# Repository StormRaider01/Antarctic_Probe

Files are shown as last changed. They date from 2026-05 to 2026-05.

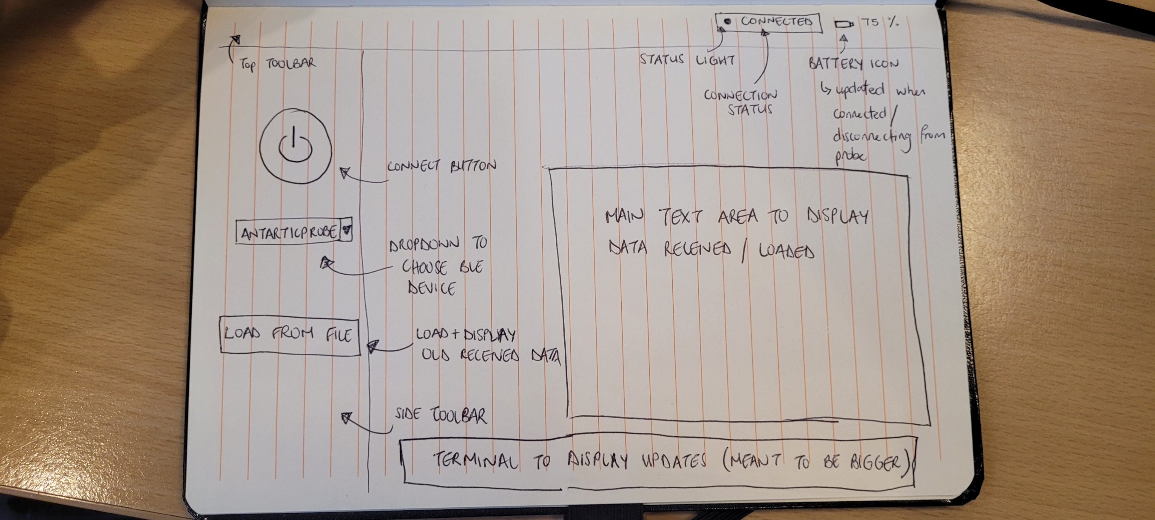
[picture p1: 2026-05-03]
GUI/GUI_idea.jpg

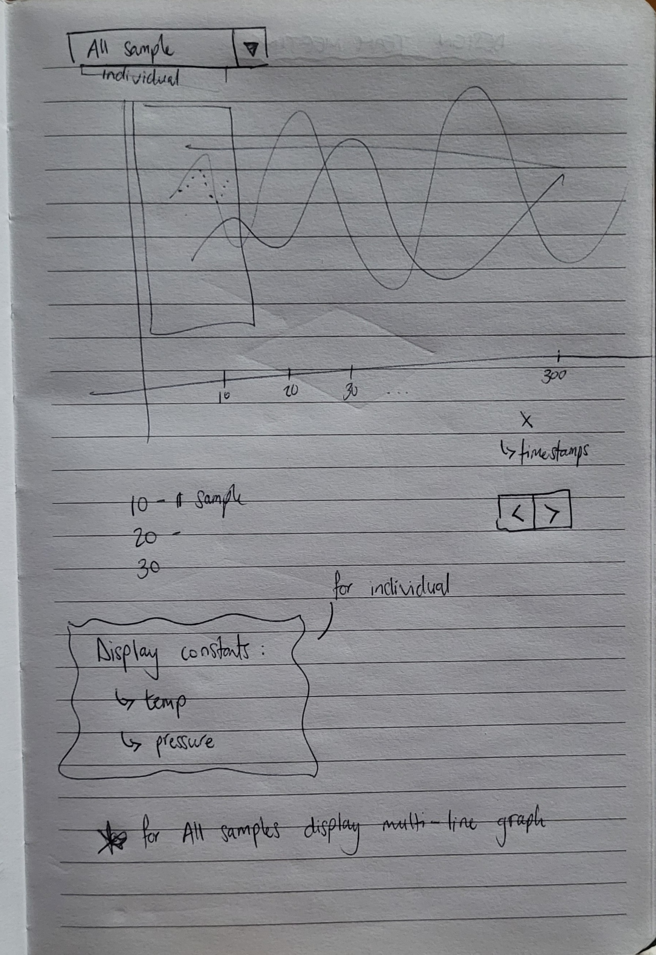
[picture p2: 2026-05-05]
GUI/Graph_tab.jpg

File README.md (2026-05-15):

# Antarctic Submersible Probe — Mission Control System

## Project Overview

This repository contains the integrated firmware, data pipeline, and GUI for a submersible Antarctic marine environmental probe system. The architecture represents the full integration of **Subsystem 1 (Wireless Communications)** and **Subsystem 2 (Edge Processing, Storage, and Machine Learning)**.

The system uses **ESP-NOW** for ultra-low-power wireless data transfer from a retrieved probe to a researcher's laptop, operating entirely **offline** with no internet dependency. Anomalies in microbial communities (detected via spectrometer spikes) are flagged instantly upon retrieval using an onboard offline Machine Learning model.

**Integrated System Flow:**
```text
Submersible Probe (ESP32-C6)
   ├── 3-State Firmware (Deep Sleep, Log, Offload)
   ├── Sensor readings parsed into 15-channel strings
   └── F-RAM (Simulated via RTC Memory)
        │
        │  [ESP-NOW Binary Protocol — ProbeRecord_t]
        ▼
Receiver Dongle (ESP32-C6 connected via USB)
   ├── Validates Checksums & Returns ACKs
   └── Serialises struct into CSV strings
        │
        │  [Serial/USB: 115200 baud]
        ▼
Local Mission Control GUI (Python)
   ├── Auto-connects to receiver dongle
   ├── Parses incoming data streams concurrently
   ├── Executes Scikit-Learn Isolation Forest Inference
   └── Visually flags [ANOMALY DETECTED] on GUI graphs
```

---

## Repository Structure

```text
├── Data Transfer Subsystem/
│   ├── Probe/
│   │   ├── Antarctic_probe.ino      # Main 3-state firmware loop
│   │   ├── espnow_transfer.cpp/.h   # ESP-NOW transmission logic
│   │   ├── fram_manager.cpp/.h      # F-RAM logging and struct parsing
│   │   └── data_packet.h            # Shared binary wire format (15 fields)
│   └── Receiver/
│       └── receiver_dongle.ino      # ESP-NOW receiver and Serial forwarder
└── GUI/
    ├── GUI.py                       # Main frontend dashboard
    ├── Backend.py                   # Serial comms, async sync_probe, anomaly evaluation
    └── ml_backend/                  
        ├── anomaly_detector.py      # MarineAnomalyDetector class wrapper
        ├── train_model.py           # Isolation Forest training script
        ├── generate_dummy_data.py   # Synthesises 15-channel marine data
        └── anomaly_model.joblib     # Persisted offline ML model
```

---

## Technical Architecture

### 1. Firmware & Storage (SS2)
- **Non-Blocking Architecture:** The probe operates a strict 3-state loop (`DEEP_SLEEP`, `WAKE_AND_LOG`, `OFFLOAD`). It uses hardware timer wakeups and GPIO interrupts (reed switch) to eliminate `delay()` calls entirely, preserving the LTO battery.
- **F-RAM Simulation:** Sensor arrays (Temp, Pressure, and 11x Spectrometer channels) are saved to RTC memory across deep sleep cycles to simulate high-speed, non-volatile F-RAM.
- **Data Packaging:** When retrieved, `fram_manager.cpp` inflates the stored strings back into binary `ProbeRecord_t` structs (incorporating 11 spectrometer arrays) for transmission.

### 2. ESP-NOW Wireless Transfer (SS1)
- **Binary Wire Format:** Uses packed C-structs (`ProbeRecord_t`) with XOR checksums to maximize MTU efficiency over the 2.4GHz spectrum.
- **Reliability:** Implements application-layer ACKs and automatic retries to ensure no packet drops between the probe and receiver dongle.

### 3. Mission Control GUI & Backend (SS1 + SS2)
- **Concurrency:** `Backend.py` uses threaded asynchronous loops to ensure the `customtkinter` frontend remains responsive while streaming high-speed serial data.
- **Auto-Discovery:** Performs DTR/RTS serial handshaking to locate the ESP32 receiver dongle automatically without manual COM port selection.

### 4. Edge Machine Learning (SS2)
- **Algorithm:** An Unsupervised `IsolationForest` identifies outliers based on 13 environmental features (dropping timestamps/IDs).
- **Inference Speed:** Executed directly on incoming serial packets within `Backend.py` via `anomaly_detector.py`. Average inference time is < 0.02 seconds per packet, satisfying real-time mission constraints.
- **Visualisation:** The GUI parses the boolean `is_anomaly` flags to plot outlier samples in high-contrast red over the Matplotlib telemetry graphs.

---

## How to Run

### 1. Setup the Hardware
1. Flash `Antarctic_probe.ino` to the primary ESP32-C6 (Probe).
2. Flash `receiver_dongle.ino` to the secondary ESP32-C6 (Receiver).
3. Connect the Receiver to your laptop via USB.

### 2. Setup the Python Environment
```bash
cd GUI
pip install -r requirements.txt
# Ensure scikit-learn, pandas, numpy, serial, customtkinter, matplotlib are installed
```

### 3. Start Mission Control
```bash
python GUI.py
```
- Click **"Connect"**. The backend will automatically handshake with the receiver dongle.
- Click **"Retrieve Data"**. 
- Simulate the probe retrieval by triggering GPIO 9 (Reed Switch) on the probe hardware. The F-RAM records will transfer wirelessly, be evaluated by the ML model, and plot directly to the dashboard.

### 4. Software Simulation Mode (Dev Mode)
If you do not have the physical hardware connected, you can simulate the full data processing and ML pipeline locally:
- Open the GUI (`python GUI.py`).
- Click **"🧪 Dev Mode: Simulate"** in the sidebar.
- The GUI will ingest the local synthetic dataset (`dummy_marine_data.csv`), simulating an ESP-NOW data stream at 0.5-second intervals. 
- Use the **Playback Control Panel** (Pause/Play, Restart, Stop) that appears to interactively control the simulation flow. Watch the graphs update live and verify the red anomaly flags without needing the physical ESP32 boards.

### 5. Hardware-in-the-Loop (HITL) Debug Mode
For physical validation without physical sensors or a magnetic switch:
1. Open `Data Transfer Subsystem/Probe/Antarctic_probe.ino`.
2. Ensure `#define DEBUG_MODE 1` is set at the top.
3. Flash the firmware to your ESP32-C6.
4. **Timer Validation**: Watch the Serial Monitor. The board will wake every 5 seconds, log a dummy record to RTC memory, and return to sleep.
5. **Interrupt Validation**: Press the physical **BOOT button** (GPIO 9) on the FireBeetle 2. This simulates the magnetic reed switch. Upon waking, the board will enter the `OFFLOAD` state and dump all accumulated RTC memory records to the Serial Monitor.

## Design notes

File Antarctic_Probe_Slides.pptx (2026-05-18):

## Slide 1

Antarctic Microbial Sensor

Autonomous Marine Environmental Monitoring System

EEE4113F · Group 14 · University of Cape Town

Devon Clark · Joshua Naidoo · Kiyuran Naidoo · Saeed Solomon

Supervised by Dr Emma Rocke · MARiS, UCT

May 2026

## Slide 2

Background & Motivation

Why does Antarctic marine monitoring matter?

THE OCEAN'S EARLY-WARNING SYSTEM

• Marine microbes are the 'invisible engines' of the ocean ecosystem
• They are the first biological indicators of climate change and pollution
• Dr Emma Rocke (MARiS, UCT) studies microbial dynamics across Antarctic & Southern Oceans
• Early detection of harmful algal blooms requires continuous, high-resolution data

THE 'WINTER DATA GAP'

• Current practice relies on expensive, infrequent research cruises
• Austral winter (-30 °C, expanding sea ice) makes the region inaccessible for months
• This creates a critical 'winter data gap' — the time most valuable for early warnings
• Human presence in the Antarctic is hazardous, costly, and logistically prohibitive

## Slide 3

Project Objectives

Design a low-cost, autonomous bipartite marine monitoring system

① Continuous Sensing

Acquire chlorophyll-a fluorescence, temperature, and depth as microbial community proxies

② Reliable Storage

Store sensor data in non-volatile memory under extreme sub-zero conditions during a dive

③ Wireless Offload

Transfer stored data wirelessly to a researcher's laptop upon probe retrieval — no physical port

④ Offline Intelligence

Process data locally using ML anomaly detection to identify ecological events — fully offline

⑤ Annual Autonomy

Sustain operation for up to 12 months on a single primary battery without human maintenance

⑥ Low Cost & Safe

Total component cost ≤ R2 000; hand-deployable by one non-specialist from a vessel of opportunity

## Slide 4

System Architecture Overview

A bipartite store-and-forward system deployed from vessels of opportunity

The system comprises two hardware nodes and one software platform. The submersible probe collects data autonomously underwater, then offloads wirelessly to a USB dongle connected to the researcher's laptop.

SUBMERSIBLE PROBE

• ESP32-C6 (FireBeetle 2)
• FRAM non-volatile storage
• AS7341 spectral sensor
• DS18B20 temperature
• Pressure/depth sensor
• Li-SOCl₂ primary battery
• Thermal insulation shell

ESP-NOW WIRELESS LINK

• Connectionless data-link protocol
• 100 m range; ultra-low power
• CRC-16 packet integrity check
• Reed switch wakeup from deep sleep
• ACK/NACK retry mechanism
• < 60 s full data offload

MISSION CONTROL (LAPTOP)

• Receiver dongle (ESP32-C6 via USB)
• Python GUI (CustomTkinter)
• Raw data table + interactive graphs
• Isolation Forest + XAI anomaly detection
• Save / load session files
• 100 % offline — no internet required

⇌ ESP-NOW

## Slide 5

Subsystem 1 — Data Transfer & Visualisation

Saeed Solomon · ESP-NOW wireless protocol + Mission Control GUI

PROTOCOL SELECTION

• NFC — ruled out: strict proximity & orientation requirements
• BLE — implemented but abandoned: ESP32-C6 stack immaturity
• ESP-NOW — selected: proven reliability, 100 m range, ultra-low power

PROBE COMMAND FLOW

• [CMD]:CONNECT — verify link, update battery level on GUI
• [CMD]:PREPARE — reset FRAM, store session timestamp
• [CMD]:RETRIEVE — stream all records with CRC-16 check
• [CMD]:DISCONNECT — power down radio to conserve battery

RESULTS

• 1.2 % avg data error (spec: < 5 %)
• 8 s wake-to-advertising (spec: < 10 s)
• All 7 ATPs passed

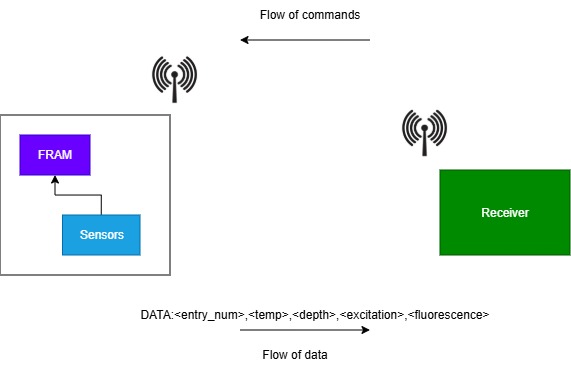
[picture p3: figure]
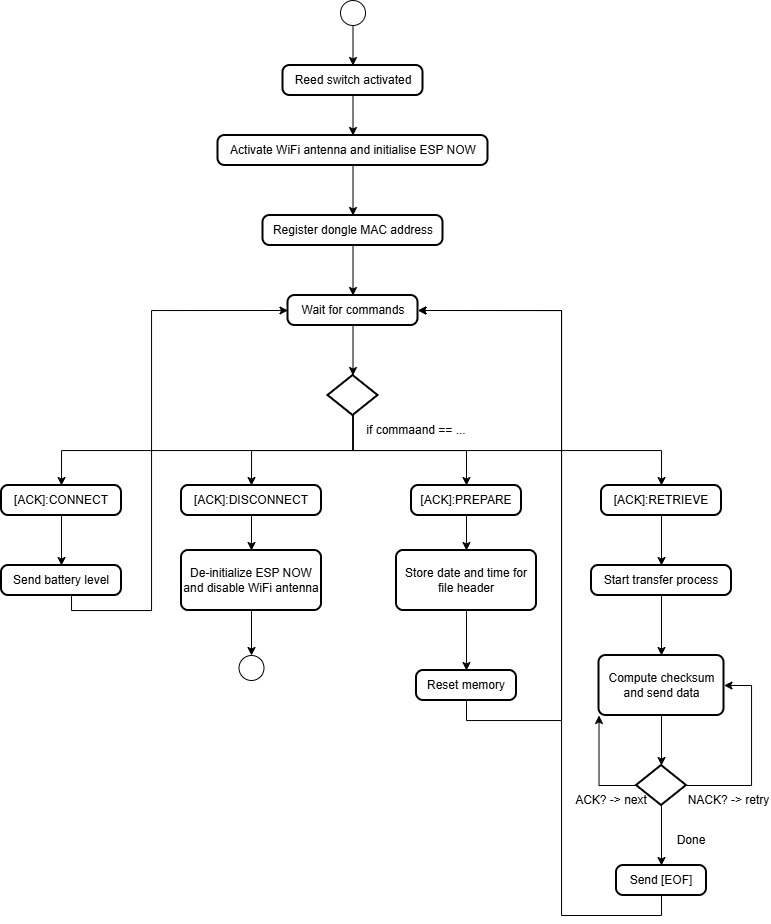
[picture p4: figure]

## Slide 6

Mission Control GUI

Fully offline Python desktop application — CustomTkinter + Matplotlib

KEY FEATURES

• Top toolbar shows connection status and battery percentage
• Sidebar: Connect / Prepare Dive / Retrieve Data / Dev Mode / Save & Load
• Raw Data tab — scrollable table of all 14 sensor channels per record
• Graph tab — interactive time-series with All Samples or per-Group view
• Status log at the bottom prints timestamped system events
• Anomaly markers (red dots) overlaid on graphs by the ML backend

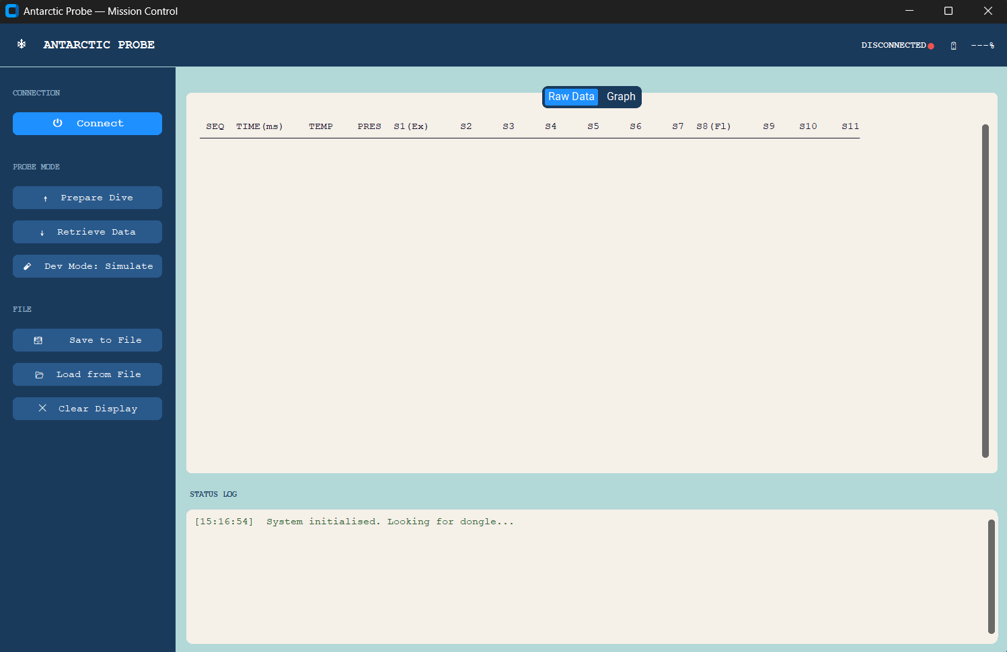
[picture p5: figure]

Raw Data tab

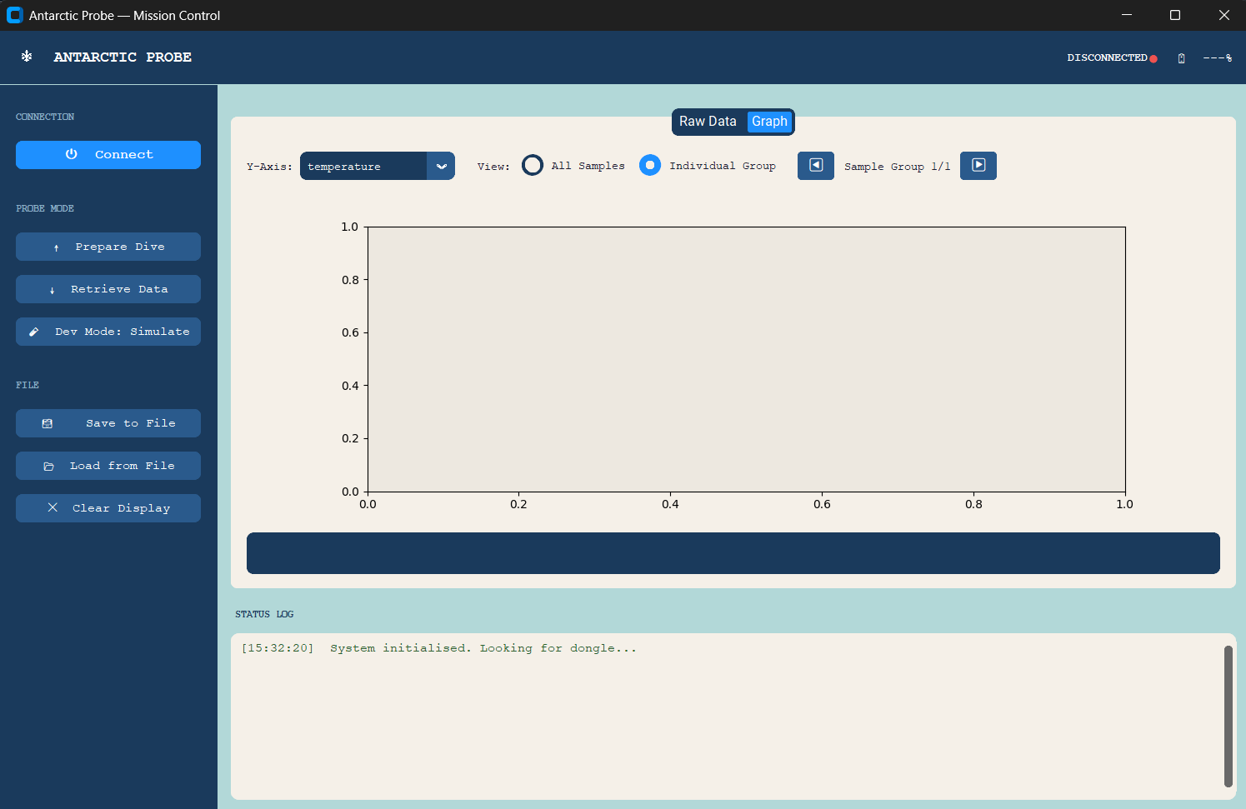
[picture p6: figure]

Graph tab

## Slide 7

Subsystem 2 — Edge Architecture & Explainable AI

Kiyuran Naidoo · On-probe firmware lifecycle + offline ML anomaly detection

4-STATE FIRMWARE LIFECYCLE

• STATE_IDLE — deep sleep on LP-IO, woken by magnetic reed switch
• STATE_ARMED — sinking delay (15 min) before data acquisition begins
• STATE_LOGGING — periodic measurement cycles; records written to FRAM
• STATE_OFFLOAD — activates ESP-NOW; awaits [CMD]:RETRIEVE from GUI

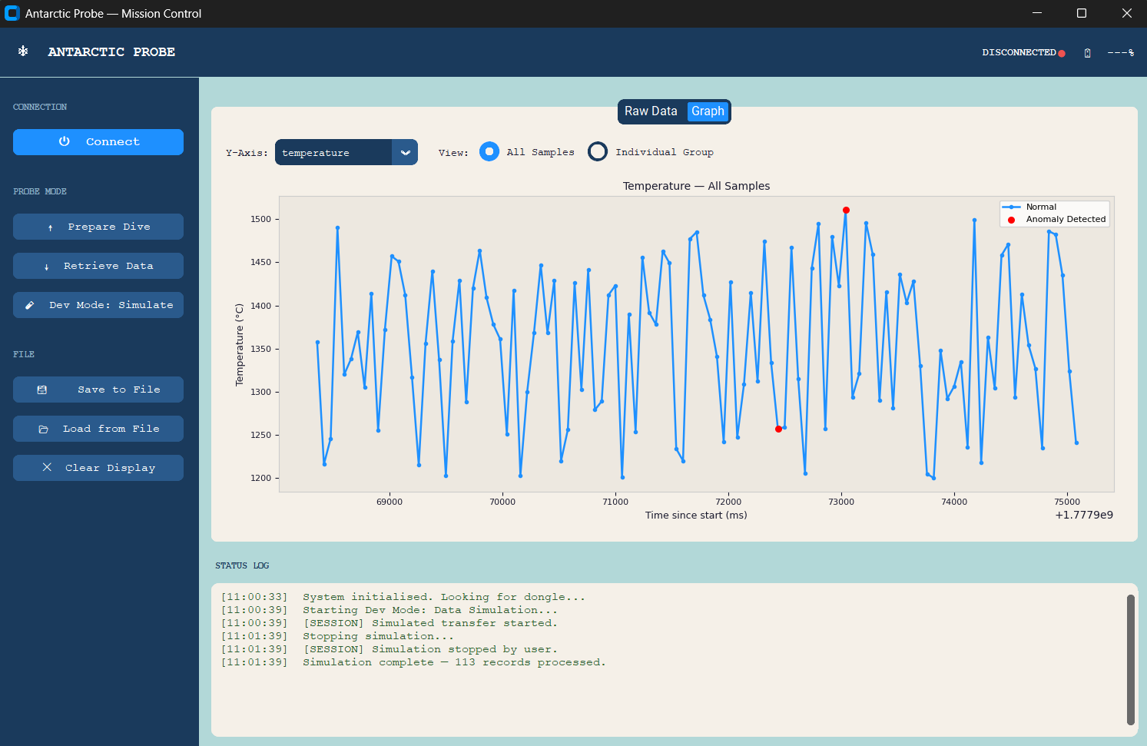
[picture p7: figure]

Mission Control graph: 113 records with anomalies flagged in red by the MarineAnomalyDetector

MEMORY — FERROELECTRIC RAM (FRAM)

• 10 mA write current vs 100 mA for SD card
• Operating range: -55 °C to +85 °C
• Data preserved across deep sleep resets (RTC SRAM)
• 58-byte fixed MTU per record, 14 sensor values

EXPLAINABLE AI (XAI) ENGINE

• Isolation Forest: anomaly isolation via random decision trees — O(n log n)
• Post-hoc deterministic ruleset: classifies Phytoplankton / Cyanobacteria / CDOM
• 92 % accuracy, 0 false positives, ~0.008 s inference (spec: < 2 s)

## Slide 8

Subsystem 3 — Power & Thermal Management

Joshua Naidoo · 365-day autonomy in Antarctic cryogenic conditions

Split-rail power schematic: ER14505 battery → MCP1700 LDOs → ESP32-C6 + FRAM + Sensors

ENERGY ARCHITECTURE

• ER14505 Li-SOCl₂ battery — operational down to -55 °C
• Nominal 2 400 mAh; 50 % capacity derated for -50 °C
• MCP1700 LDO: 1.6 µA quiescent vs 5 mA for LM7805
• FireBeetle 2 ESP32-C6: 10 µA deep sleep vs 10 mA (DevKit)
• Split-rail: 3.3 V always-on rail + 5 V switched sensor rail
• P-MOSFET (AO3401A) power gate — GPIO-controlled sensor isolation
• ~22 measurement cycles/day over 365-day mission verified

THERMAL 'HUDDLE' STRATEGY

• Layer 1 — Aluminium foil tape: reflects infrared radiation
• Layer 2 — EWELDH010 foam: stagnant air pockets, high thermal resistance
• RF window: 20 mm foil gap allows 2.4 GHz ESP-NOW signal to escape
• MCP1700 regulators thermally bonded to battery stack (self-heating)
• Result: internal core held at -12 °C after 6 h cold-soak at -30 °C
• 16.8 µA measured standby current — within 20 µA specification

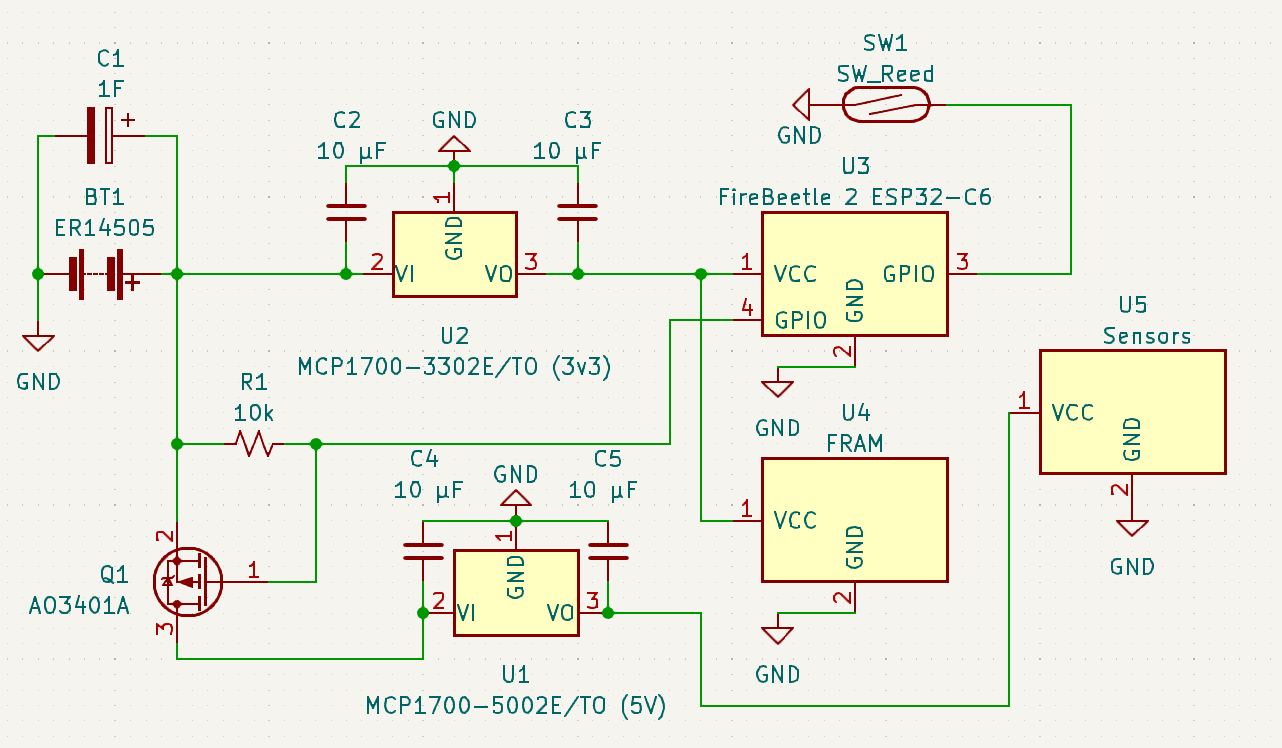
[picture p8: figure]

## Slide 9

Subsystem 4 — Sensors & Housing

Devon Clark · Chlorophyll fluorometer, temperature, depth, waterproof PVC enclosure

SENSOR SUITE

• AS7341 — 11-channel spectral sensor; 445 nm excitation, 680 nm fluorescence channels
• CZ104BC — 460 nm blue LED excitation (5 500–6 000 mcd); matches chlorophyll-a peak
• DS18B20 — waterproof 1-Wire digital; factory-calibrated; ±0.4 °C achieved
• Analog pressure sensor — 0–120 m range; R² > 0.99 depth linearity
• 11-step PWM ramp algorithm to optimise fluorometer sensitivity

WATERPROOF HOUSING

• 50 mm OD PVC pipe main body (46.8 mm ID, 250 mm length)
• FDM 3D-printed PLA end caps with 4 perimeters (SLA recommended for production)
• Friction-fit double O-ring seal — field serviceable, no tools required
• Negatively buoyant — self-sinking with ballast weights
• Waterproof to 1 m for 30 min (prototype validation)
• Total system cost: < R2 000 · Mass: < 1 kg

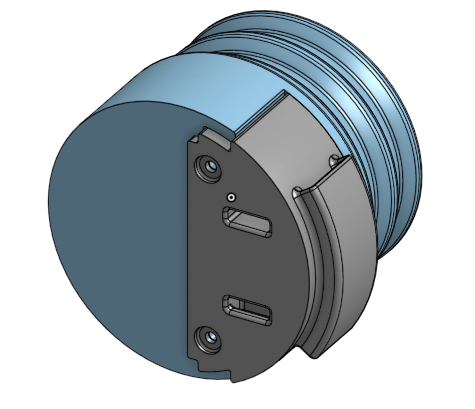
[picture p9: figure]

Rear end cap (sealed side)

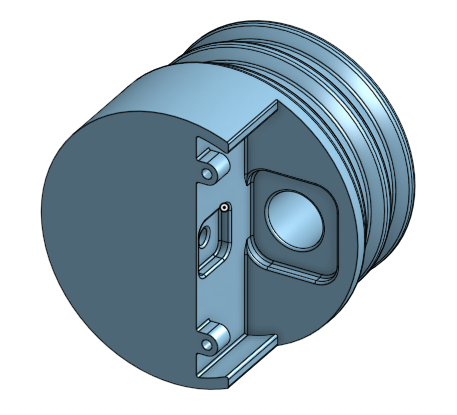
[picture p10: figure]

Front end cap (sensor window side)

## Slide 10

System Results & Validation

All subsystem acceptance test procedures passed

Data Transfer
& Visualisation

• 1.2 % avg data error (spec: < 5 %)
• 8 s wake-to-advertising (spec: < 10 s)
• 100 m operational range (spec: > 10 m)
• All 7 ATPs passed
• Fully offline GUI operation confirmed

Edge Architecture
& Explainable AI

• FRAM data intact across all deep sleep cycles
• 4-state lifecycle validated via HITL serial telemetry
• 92 % XAI classification accuracy, 0 false positives
• 0.008 s inference per record (spec: < 2 s)
• All 4 ATPs passed

Power & Thermal
Management

• 16.8 µA measured standby (spec: ≤ 20 µA)
• -12 °C core after 6 h cold-soak at -30 °C
• 3.3 V & 5.0 V rails stable across full discharge
• P-MOSFET gate: sensor current drops to 0 µA on GPIO
• All 5 ATPs passed

Sensors
& Housing

• Fluorescence ratio monotonically increases down to 1/32 dilution
• Temperature accuracy ±0.4 °C (spec: ±0.5 °C)
• Depth linearity R² > 0.99 (spec: R² > 0.99)
• Waterproof at 1 m for 30 min — no ingress
• All 8 ATPs passed · Total cost < R2 000

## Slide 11

Conclusions & Future Work

A functional, integrated Antarctic monitoring system demonstrated across all four subsystems

CONCLUSIONS

• A fully integrated bipartite probe system was designed and demonstrated
• Sensor data is acquired, stored in FRAM, and wirelessly offloaded to a laptop GUI
• ML-based anomaly detection operates entirely offline on standard hardware
• System is hand-deployable by one non-specialist from a vessel of opportunity
• Annual autonomy validated through energy modelling and cold-soak testing
• Total cost within R2 000 budget; fits within 50 mm OD PVC housing
• All 24 acceptance test procedures across four subsystems passed

FUTURE WORK

• Migrate to BLE once ESP32-C6 NimBLE stack matures (remove dongle requirement)
• SLA resin end caps for long-term immersion (replace FDM PLA)
• Absolute chlorophyll calibration using field samples
• Extend depth rating beyond 2 m prototype limit
• Add dissolved oxygen & nutrient sensors within revised budget
• LoRaWAN / NVIS relay from docking station to mainland research facility
• Satellite uplink for real-time data access during deployment

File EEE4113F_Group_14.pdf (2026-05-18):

# Antarctic Microbial Sensor

# Group 14


Prepared by:
Devon Clark
Joshua Naidoo
Kiyuran Naidoo
Saeed Solomon

Prepared for:
EEE4113F
Department of Electrical Engineering University of Cape Town

May 18, 2026

# Declaration

1. I know that plagiarism is wrong. Plagiarism is to use another’s work and pretend that it is one’s own.
2. I have used the IEEE convention for citation and referencing. Each contribution to, and quotation in, this report from the work(s) of other people has been attributed, and has been cited and referenced.
3. This report is my own work.
4. I have not allowed, and will not allow, anyone to copy my work with the intention of passing it off as their own work or part thereof.

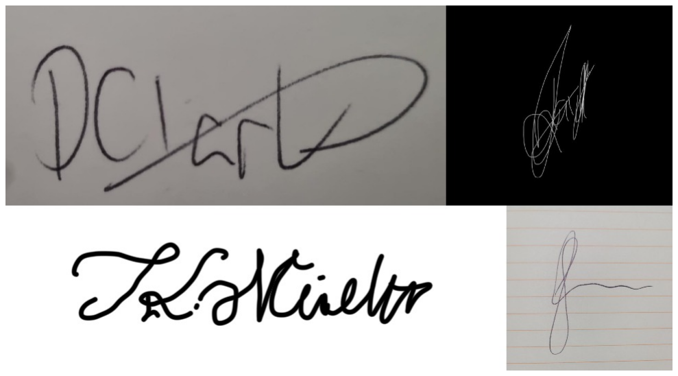
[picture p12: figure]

May 18, 2026

Devon Clark | Joshua Naidoo | Kiyuran Naidoo | Saeed Solomon Date

ii

# Contents

Abbreviations | vii
1 Introduction | 1
2 Literature Review | 3
3 Data Transfer and Visualisation | 14

iii

Contents

4 Edge Architecture and Explainable AI | 26
4.7.1 | Onboard Firmware and State Machine Verification (ATP-01 and ATP-02) . . . | 33
4.7.2 | Localised Edge Machine Learning and XAI Engine Validation (ATP-03 and
5 Power and Thermal Subsystem | 36

iv

Contents

6 Sensors and Housing | 45
7 Conclusions | 54

v

Contents

8 Recommendations | 56
9 Appendix | 60
A Dev Mode: Simulated Data Screenshots | 61
B Evidence of GA | 64
Bibliography | 65

vi

# Abbreviations

ANN Artificial Neural Network

ATP Acceptance Test Procedure

BLE Bluetooth Low Energy

CNN Convolutional Neural Network

CTD Conductivity, Temperature, Depth

DL Deep Learning

DMS Data Management Subsystem

ECR Edge Computing-RESTful

eNVM Embedded Non-Volatile Memory

GUI Graphical User Interface

IDE Integrated Development Environment

IoT Internet of Things

LAMP Loop-Mediated Isothermal Amplification

LED Light Emitting Diode

LoRaWAN Long Range Wide Area Network

LPWAN Low-Power Wide-Area Network

MEMS Micro-Electro-Mechanical Systems

ML Machine Learning

MRAM Magnetoresistive Random Access Memory

NFC Near-Field Communication

NVIS Near Vertical Incidence Skywave

vii

Abbreviations

PCB Printed Circuit Board

PCM Phase Change Materials

PDMS Polydimethylsiloxane

ROV Remotely Operated Vehicle

SLA Stereolithography

STT-MRAM Spin-Transfer Torque MRAM

SVM Support Vector Machine

SWPDT Simultaneous Wireless Power and Data Transfer

UI User interface

USB-C Universal Serial Bus Type-C

USV Unmanned Surface Vehicle

Wi-Fi Wireless Fidelity

viii

# Chapter 1

# Introduction

### 1.1 Background

Marine microorganisms are the foundational drivers of the ocean ecosystem, mediating global biogeochemical cycles and acting as the first responders to environmental stressors such as climate change and anthropogenic pollution. As Dr Emma Rocke, a marine microbiologist at the Marine and Antarctic Research for Innovation and Sustainability (MARiS) institute at the University of Cape

Town, describes it: “Microbes are the invisible engines of the ocean ecosystem.” Her research spans the Benguela Upwelling System, the Indian Ocean, and the Antarctic and Southern Ocean, where microbial community dynamics serve as the earliest available proxy for broader ecological shifts.

Gathering the continuous, high-resolution data required to detect these shifts presents a fundamental challenge in the Antarctic region. Current practice relies on research cruises that are expensive, infrequent, and offer only limited spatial coverage. The austral winter exacerbates this shortfall severely: expanding sea ice, temperatures routinely below −30 ◦C, and inclement weather render the

region physically inaccessible for months at a time, creating what is widely termed the winter data gap. Critically, this period of observational absence coincides with the time at which early detection of harmful algal blooms and ecosystem disturbances would be most valuable. The reliance on human operators to bridge this gap exposes researchers to acute physical danger, extreme psychological strain, and high logistical cost, while still failing to produce the temporal continuity the science demands.

### 1.2 Objectives

The primary objective of this project is to design and demonstrate a low-cost, autonomous bipartite marine environmental monitoring system that can be deployed from vessels of opportunity — including fishing vessels, sailing yachts, and research cruises — by non-specialist operators, thereby removing the need for dedicated human presence in hazardous Antarctic conditions. The system must:

1. Acquire continuous optical and physical sensor data (chlorophyll-a fluorescence, temperature, and depth) as proxies for microbial community dynamics.
2. Store acquired data reliably in non-volatile memory under extreme sub-zero conditions for the duration of a dive.
3. Transfer the stored data wirelessly to a researcher’s laptop upon probe retrieval, without requiring

1.3. System Requirements

a physical port on the probe enclosure.

4. Process the retrieved data locally, using machine learning anomaly detection to identify ecologically significant events entirely offline.
5. Sustain operation for up to twelve months on a single primary battery set without human maintenance.

### 1.3 System Requirements

The system must operate across two extreme thermal regimes: seawater approaching −1.8

◦C during
submersion and ambient air down to −30 ◦C upon retrieval to the vessel deck. The probe enclosure

must withstand shallow-water pressure without water ingress, and all electronics must remain functional throughout. The complete system must fit within a 50 mm outer-diameter PVC pipe housing, be hand-deployable by a single operator, and have a total component cost not exceeding R2000. Data transfer between the probe and the laptop must complete within 60 seconds of connection, and the Mission Control graphical user interface must operate fully offline without any dependency on internet connectivity.

### 1.4 Scope and Limitations

This project addresses the sensor-to-laptop data pipeline and does not extend to long-range satellite transmission to mainland research facilities, which is identified as future work. The prototype targets near-surface deployments of up to 2 m depth; the design is architecturally scalable to greater depths but hardware validation at depth is beyond the present scope. Dissolved oxygen and nutrient sensors are excluded due to budget constraints, with chlorophyll-a fluorescence retained as the primary microbial proxy. Wireless charging of the probe battery, initially proposed as part of the docking station concept, was descoped following the removal of the docking station from the architecture; the probe instead uses a primary Lithium Thionyl Chloride battery rated for twelve months of autonomous operation.

### 1.5 Report Outline

This report is structured as follows. Chapter ?? presents the literature review, surveying candidate data transmission protocols, embedded memory architectures, extreme-cold power systems, and marine sensing and housing methodologies to ground each design decision in the existing body of knowledge. Chapters ?? through ?? cover the four engineering subsystems in depth: Data Transfer and Visualisation (Chapter ??), Edge Architecture and Explainable AI (Chapter ??), Power and Thermal Management (Chapter ??), and Sensors and Housing (Chapter ??). Each chapter follows a consistent structure: requirements analysis, design choices with justification, final implementation, and acceptance test results. Chapter 7 draws overall conclusions and Chapter 8 identifies directions for future work.

# Chapter 2

# Literature Review

### 2.1 Introduction and Operational Context

The Antarctic marine ecosystem plays a critical role in global climate regulation, with marine microbes acting as the ocean’s primary early warning system for environmental shifts and pollution. However, gathering continuous, real-time biological data in this region is severely constrained by the ‘winter gap’, a period where extreme cold, sea-ice expansion, and severe weather make traditional research cruises prohibitively dangerous and expensive. Consequently, the reliance on infrequent manual sampling exposes marine researchers to immense physical and psychological risks while leaving vast spatial and temporal gaps in the ecological data pipeline.

To address this observational bottleneck without relying on highly complex, fully autonomous ocean gliders, a bipartite measurement system deployed from ‘vessels of opportunity’ (such as research cruises, fishing vessels or sailing yachts) presents a highly feasible engineering solution. This concept comprises a deck-bound docking station and a submersible measurement probe. The probe is lowered into the ocean via a tether to log localised environmental data, after which it is retracted to the docking station to securely transfer the telemetry for advanced on-board processing.

Operating a sophisticated electronic system in an environment where ambient temperatures drop below -30°C and seawater approaches -1.8°C introduces severe, multi-disciplinary engineering challenges. This literature review evaluates current academic research to inform the design of this bipartite system. The review is structured to analyse four critical domains: short-range data transmission protocols to bridge the two subsystems (Section 1.2), edge computing architectures and robust embedded memory to manage the massive datasets (Section 1.3), specialised battery chemistries and thermal management techniques to ensure survivability (Section 1.4), and the physical sensing modalities, waterproofing, and tethering mechanics required for reliable marine deployment (Section 1.5).

### 2.2 Data Transmission Subsystem

Operation of electrical systems in the extreme environmental conditions of Antarctica presents numerous engineering challenges. Liu et al. identifies sensor drift, packaging cost, and sea-water corrosion as significant factors that affect system performance in such climates [1]. Similarly, Uhm et al. highlights the necessity of active temperature control and thorough insulation of internal hardware to sustain the prolonged operation of a robotic system tested in Antarctica [2]. These findings highlight the dangers

2.2. Data Transmission Subsystem

posed by exposed ports or incomplete enclosures, which can allow the harsh Antarctic environment to compromise internal components. The following subsections examine candidate data transmission methods for communication between the measurement probe and the main docking station subsystem.

### 2.2.1 Wired Protocols

A tethered connection between the measurement probe and the docking station was initially proposed to enable real-time data communication. However, several critical concerns were identified: the potentially large and variable distance a tether would need to span depending on whether the solution is deployed on a large research vessel or a smaller fishing vessel; signal integrity degradation over long cable runs; and the exorbitant cost of thermally insulated, electrical cabling needed to transmit data in the Antarctic cold. Additional concerns included the risk of undetected faults developing over time due to limited maintenance access, which could result in silent data loss or corruption. For these reasons, long-range tethered solutions were ruled out in favour of short-range wired protocols to transfer data between the two subsystems once the measurement probe has returned from deployment. Table 2.1 summarises the characteristics of several candidate short-range wired protocols [3].

Name | Duplex | Max speed (Kbps) | Max distance (ft)
RS-232 | Full | 20 | 30
RS-422 | Half | 10000 | 4000
RS-485 | Half | 10000 | 4000
2C I | Half | 3400 | <>
SPI | Full | > 1000 | <>

Table 2.1: Short-range wired protocol comparison [3]

A further short-range protocol not listed in Table 2.1 is Universal Serial Bus Type-C (USB-C), which has become a widely adopted industry standard owing to its plug-and-play capability, high data transfer speeds, and versatility across connection types [3].

### 2.2.2 Wireless Protocols

Because the measurement probe operates while submerged and the docking station remains above the waterline, long-range wireless communication between them during deployment is not feasible. This is primarily due to the pronounced difference in electromagnetic signal propagation between water and air, which severely attenuates radio-frequency signals at depth [4]. Consequently, a short-range wireless protocol - employed once the measurement probe has surfaced and returned to the docking station
- represents the most viable wireless approach. A long-range wireless solution was also considered, following the approach of Porte et al., who employed Near Vertical Incidence Skywave (NVIS) to relay data directly to a remote research station [5]. This architecture would have eliminated the need for a docking station subsystem entirely by transmitting data directly to a research base. However, it would have imposed significantly greater power, environmental protection and hardware requirements on the measurement probe, including the need for the either human personnel or another subsystem to ensure the positioning for NVIS to take place [5]. Although this approach was not adopted for

2.3. Edge Architecture and Data Management

the measurement probe, it remains a viable option for the docking station subsystem to relay data onward after the initial sensor-to-docking-station transfer. Table 2.2 presents a comparison of candidate short-range wireless protocols, based on the comparative study conducted by Vidakis et al. [6].

Name | Range (m) | Frequency | Transmission time (s) | Power consumption
Bluetooth | 100 | 2.4 GHz | 24 Mbit/s | Medium
BLE | 60 | 2.4 GHz | 2 Mbit/s | Low
NFC | < 0.2 | 13.56 MHz | 424 kbit/s | Low
Wi-Fi Direct | 100 | 2.4 GHz, 5 GHz | 250 Mbit/s | High

Table 2.2: Short-range wireless protocol comparison [6]

Of the protocols considered, Near-Field Communication (NFC) best satisfies the data transfer requirements of this application while minimising power consumption. By utilising a pair of inductive coils, an NFC interface can serve a dual function: transferring the recorded sensor data and simultaneously providing wireless charging capability [7]. Critically, this eliminates the need for a physical charging and data port on the measurement probe, which in turn permits a fully sealed enclosure and enhanced protection against the Antarctic environment. Although Simultaneous Wireless Power and Data Transfer (SWPDT) - the concurrent transfer of power and data over a single inductive link - remains an active area of research and is considered beyond the scope of this project [8], sequential operation (data transfer followed by charging, or vice versa) is readily achievable with existing NFC technology.

### 2.3 Edge Architecture and Data Management

The acquisition of high-fidelity environmental data by the submersible probe represents only the first phase of the system’s operational pipeline. Once gathered, this data must be securely stored, efficiently managed, and rapidly analysed to provide actionable ecological insights without overwhelming limited communication networks. This section investigates the hardware and software architectures required to process the massive datasets generated during Antarctic deployments. First, it explores robust embedded memory solutions capable of preserving data integrity in extreme sub-zero conditions before the probe docks. It then examines the necessity of edge computing frameworks, which bypass severe satellite bandwidth limitations by migrating computational tasks to the surface-level docking station. Finally, it reviews the application of machine learning and deep learning algorithms for in situ data processing, which enables the autonomous detection of microbial community shifts and environmental anomalies directly on the vessel.

### 2.3.1 Embedded Memory Solutions

The Antarctic marine monitoring system relies on a submersible measurement device that must continuously record and preserve critical biological and oceanographic data (such as conductivity, temperature, depth, and dissolved oxygen) before ascending to the surface docking station. Operating in seawater temperatures that can drop to -1.8°C and experiencing atmospheric exposure down to -30°C upon retrieval, the embedded memory must guarantee absolute data integrity. Traditional volatile memory is unsuitable due to data loss upon power failure, which necessitates the use of non-volatile

2.3. Edge Architecture and Data Management

storage. However, conventional commercial storage solutions, such as standard SD cards based on NAND flash, are highly susceptible to thermal degradation, reduced write endurance, and charge leakage in extreme environments.

To achieve maximum system reliability, compactness, and low power consumption, Embedded Non-Volatile Memory (eNVM) directly integrated into the microcontroller die is highly advantageous. A comprehensive architectural review of eNVM highlights the trade-offs between legacy technologies, such as EEPROM and Flash [9]. While floating-gate EEPROM allows for byte-level rewriting, ideal for precise sensor data logging, it suffers from slower write speeds and higher power consumption compared to Flash [9]. Conversely, NAND flash offers higher density but operates using charge pumps to trap electrons on an electrically isolated gate. In extreme cold, charge mobility decreases, which can severely impede flash read/write operations and increase processing latency.

To mitigate the thermal vulnerabilities of charge-based storage, emerging eNVM technologies such as Magnetoresistive Random Access Memory (MRAM) present a superior alternative. MRAM stores data through magnetic states utilising the Tunnelling Magnetoresistance (TMR) effect rather than trapped electrons. Recent evaluations of embedded memories in cryogenic and extreme sub-zero temperatures (down to 77K) demonstrate that Spin-Transfer Torque MRAM (STT-MRAM) yields significantly higher read-voltage sensing margins in freezing conditions compared to standard SRAM [10]. By relying on magnetic polarisation, MRAM achieves near-infinite read/write endurance and maintains reliable data retention even below -40°C [10], which makes it a highly robust candidate for the Antarctic probe.

For the most extreme operational limits, purely mechanical data storage provides an innovative fail-safe. Joshi et al. detail the fabrication of a non-volatile Micro-Electro-Mechanical Systems (MEMS) switch designed specifically for harsh environments [11]. Encapsulated within a standard CMOS back-end-ofline process, this memory cell utilises a submicron refractory metal cantilever with two mechanically stable states. Data is stored physically through van der Waals stiction rather than electrical charge [11]. Because it lacks a charge-storage mechanism, this MEMS-based memory is fundamentally immune to temperature-induced charge leakage and operates reliably across an extreme thermal spectrum of -150°C to 350°C [11].

Ultimately, for the tethered Antarctic measurement device, relying solely on commercial flash memory introduces an unacceptable risk of data corruption during prolonged sub-zero deployments. The literature indicates that transitioning the probe’s on-board storage to MRAM architectures [10], or integrating MEMS-based non-volatile memory cells [11], provides the necessary combination of zeropower data retention, extreme thermal resilience, and high write endurance. This ensures that the captured microbial datasets securely survive the harsh conditions and are fully intact for inductive NFC transfer upon mating with the deck-bound docking station.

### 2.3.2 Edge Computing on Marine Hubs

Once the submersible probe safely records biological data to its non-volatile memory and returns to the surface, the system faces a severe communication bottleneck. Marine research in the Antarctic region relies almost exclusively on satellite communications to transmit data back to mainland laboratories. However, transmitting massive gigabyte-scale datasets, such as high-resolution optical fluorescence logs or continuous conductivity, temperature, and depth (CTD) profiles, over these networks is prohibitively

2.3. Edge Architecture and Data Management

expensive, slow, and highly susceptible to latency and intermittent connectivity. As highlighted in a comprehensive review of oceanographic data processing [12], classical cloud-centric architectures fundamentally fail in remote marine environments due to these bandwidth limitations. To ensure real-time environmental insights, computational power must be relocated closer to the data source, which is an approach known as edge computing.

Implementing an edge-centric architecture perfectly aligns with the proposed vessel of opportunity concept. Recent research on marine Internet of Things (IoT) network topologies proposes a threelayer edge architecture tailored specifically for underwater and surface environments [13]. In this paradigm, the deck-bound docking station acts as the critical intermediate ‘edge node’ situated between the perception layer (the submersible probe) and the cloud layer (mainland servers). By offloading the raw datasets from the probe via NFC and processing them locally on the vessel, the docking station drastically reduces the payload size. Only critical ecological anomalies, summaries, or processed metadata are transmitted over the satellite link, which fundamentally bypasses the bandwidth bottleneck [12, 13].

Beyond simply filtering data, the edge hub must manage the overall data lifecycle and system infrastructure. Chave et al. detail the necessity of a robust Data Management Subsystem (DMS) for integrated ocean observatories [14]. A highly functional DMS does not merely pass data along, but it also handles local archiving, bidirectional data routing, and metadata tagging [14]. In the context of the Antarctic deployment, the docking station’s edge architecture will append crucial contextual metadata, such as real-time GPS coordinates from the host vessel, weather conditions, and time-stamps to the biological data retrieved from the probe, which ensures absolute data provenance before long-term storage or transmission.

Furthermore, edge computing resolves a critical energy conflict within the system. Processing complex biological datasets requires significant computational overhead that would rapidly drain the submersible probe’s battery. To maximise the probe’s endurance, the system can utilise task collaborative migration methodologies. Research into Edge Computing-RESTful (ECR) architectures for marine IoT demonstrates how heavy processing tasks can be dynamically scheduled and migrated from resourceconstrained end-devices to more powerful, surface-level edge gateways [15]. By centralising the intensive data processing algorithms on the docking station, which has access to the vessel’s more stable power supply, the submersible probe can dedicate its limited energy budget entirely to maintaining sensor fidelity and executing the NFC data transfer.

Ultimately, designing the docking station as an intelligent marine edge hub rather than a passive charging cradle ensures that the massive datasets generated during the Antarctic winter gap are aggressively filtered, locally archived, and efficiently transmitted, all while preserving the power constraints of the remote sensing hardware.

### 2.3.3 Advanced Processing for Microbial Data

Once the submersible probe’s data is successfully transferred to the docking station via NFC, the edge architecture must rapidly process the raw telemetry to extract meaningful ecological insights. A core objective of the Antarctic deployment is to serve as an early warning system for microbial community shifts and harmful environmental events. Traditionally, identifying these shifts required physical

2.4. Extreme Cold Power System

water samples to be manually analysed in a laboratory setting. However, recent advancements have demonstrated that Machine Learning (ML) algorithms can successfully interpret complex, non-linear relationships in chemical and biological oceanographic data directly in situ [16].

Because the proposed measurement device utilises optical and fluorescent microsensors to detect dissolved organic matter, the data output consists of raw optical radiance and impedance values rather than explicit biological classifications. A review of ML applications in ocean colour and optical sensing highlights the efficacy of Artificial Neural Network (ANN)s and Support Vector Machine (SVM)s in translating this raw optical backscatter and fluorescence into accurate biological parameter estimates, such as phytoplankton concentration and microbial biomass [17]. By hosting these trained regression models on the docking station, the system can autonomously convert physical sensor voltages into quantitative biological data.

However, marine ecological datasets gathered in extreme environments are notoriously noisy. Sensor data can be easily skewed by ice particulates, biofouling on the optical lenses, or rapid localised temperature fluctuations. To address this, researchers are increasingly unlocking the potential of Deep Learning (DL) for marine ecology [18]. Off-the-shelf DL architectures, such as Convolutional Neural Network (CNN)s applied to one-dimensional time-series data, have proven highly effective at filtering out environmental noise and recognising cryptic patterns in ecological datasets that traditional statistical methods overlook [18].

The ultimate operational goal of the docking station’s software is anomaly detection, which is identifying the moment a baseline microbial community undergoes a stress-induced shift. Designing algorithms for this specific task is uniquely challenging. As outlined in recent studies on building ML challenges for scientific anomaly detection, models must be carefully trained to distinguish between a true scientific outlier (genuine ecological event) and a spurious anomaly (sensor malfunction or background noise) [19]. In the context of the Antarctic winter gap, an unsupervised machine learning model, such as an Isolation Forest or an Autoencoder, can be deployed on the edge hub to continuously monitor the incoming data.

By defining the ‘normal’ winter microbial baseline, the edge algorithm can flag significant deviations in real-time [19]. Consequently, the docking station does not merely archive data, but it also actively diagnoses the ecosystem, which ensures that only high-value, critical alerts regarding microbial community shifts are transmitted over the constrained satellite networks back to mainland researchers.

### 2.4 Extreme Cold Power System

In Antarctica, the environmental conditions present challenges that engineers need to consider when designing measurement devices. Some of these challenges include the ocean temperature. The Antarctic waters fall near temperatures of -1.8 degrees Celsius, and ambient temperatures falling below -30 degrees Celcius quite frequently. These conditions, specifically, degrade thermal stability, storage of energy, as well as the power delivery in engineering systems. For the two-part system consisting of both a sensing submersible probe and a deck-mounted docking station, the reliable delivery of power to both systems becomes the primary constraint of long-term operation. Conventional systems that could be used in this environment would experience difficulties with increased internal resistance, a

2.4. Extreme Cold Power System

reduction in capacity, as well as thermal inefficiencies relating to the operation of the device. Therefore, advancements in battery chemistry, thermal management, and efficient energy system design should be considered.

### 2.4.1 Battery Chemistry at Sub-Zero Temperatures

Batteries such as lithium-ion and sodium-ion will be considered. Both these batteries experience quite a significant amount of performance degradation at low temperatures (such as the temperatures in Antarctica). This performance degradation is mainly due to reduced ionic conductivity and an increased amount of charge transfer resistance. Specifically, electrolytes have an important role within the battery chemistry at low temperatures, as their ion mobility, viscosity, and melting point directly affect the battery efficiency [20]. Standard carbonate electrolyte batteries have performance issues at low temperatures, which include reduced conductivity and a large increase in interfacial resistance [20]. Current research into the field of alternative electrolyte systems suggests that carboxylate ester-based electrolytes are highly effective at low temperatures, as they possess low viscosity, low melting points (below -70 degrees Celcius), and high dielectric constants [20]. This makes them highly favourable for sub-zero environments such as Antarctica. The properties mentioned above increase the ion transport and reduce the overall charge transfer resistance, hence, improving the performance of the battery in extreme cold temperatures [20]. However, there are challenges presented when stabilizing electrode-electrolyte interfaces due to the increase in reactivity at low temperatures [20]. In addition to this electrolyte enhancement, the battery thermal sensitivity should also be considered. Batteries such as the lithium-ion cell are extremely dependent on temperature. Extreme cold can lead to reduced capacity as possible safety risks such as fire and explosion [21]. Therefore, there is a need for integrated thermal regulation strategies.

### 2.4.2 Thermal Management in Embedded Systems

Thermal management of battery systems is integral in controlling the battery efficiency, preventing thermal runaway (battery heating faster than it can dissipate the heat) [21], and ensuring the battery can operate reliably at low temperatures. Lithium-ion batteries in particular suffer from cold temperatures, which lead to poor heat dissipation, capacity fade, non-uniform cell behaviour, and possible catastrophic battery failure [21]. According to W. Wu et al., an efficient and effective passive thermal management system using Phase Change Materials (PCM). The PCM absorb and release latent heat during the change of phases [21]. This maintains relatively stable operating temperatures. Furthermore, W. Wu et al. suggest that composite PCM systems improved with materials such as graphite significantly improve the thermal conductivity as well as the heat dissipation [21]. This improves the stability of temperature across battery modules [21]. In addition to the internal temperature control of the battery, external insulation also plays a crucial role in battery survival. This would minimize heat loss in cold environments in the Antarctic, such as ship decks. According to Shahar Idan and Yuri Feldman, further researched insulation strategies, such as porous and structured materials, significantly reduces convective heat transfer by suppressing the internal air circulation and limiting temperature difference [22]. Furthermore, M. Rajendiran et al. suggest that additional insulation materials, such as nitrile rubber foam, show effective thermal resistance as well as increased thermal retention compared to vacuum insulation in some configurations, specifically when the material’s heat capacity and surface

2.5. Marine Sensing Modalities and Deployment Mechanics

temperature effects are taken into account [23]. Thermal stability is essential for sensing processes such as Loop-Mediated Isothermal Amplification (LAMP), which require stable operating temperatures, hence the need for hybrid insulation solutions [24].

### 2.4.3 Power Budgeting and Duty-Cycling

Power management within battery operation is essential for extending the battery lifetime within energy-constrained Antarctic conditions. Wireless sensor nodes, as well as embedded systems, usually operate in low-duty-cycle modes. Most of the time, these systems are spent in sleep states, which draw power. Even during sleep states, particularly when looking at voltage regulation components, can significantly reduce battery life [25]. According to D. Balsamo et al., adaptive duty-cycling techniques for DC-DC converters can provide an effective solution to this problem. This can provide dynamic control of converter activation based on the demand of the system as well as the system leakage. The process of intermittently activating the system using internal capacitor storage and only activating the converter when needed will significantly reduce the quiescent loss and hence extend battery life [25]. This approach is particularly beneficial in systems such as remote sensing nodes where sleep-mode battery consumption dominates the overall energy usage. Furthermore, the reduction of energy consumption during communication between nodes is essential. Solutions such as low-power communication protocols and improved scheduling will further reduce the overall energy demand. Communication protocols also play a critical role in overall system energy consumption. Standard wireless technologies such as Wireless Fidelity (Wi-Fi), Bluetooth, and ZigBee all consume a high amount of power when in use and have limited coverage [26]. Constrastingly, technologies known as Low-Power Wide-Area Network (LPWAN), which include Long Range Wide Area Network (LoRaWAN), enable long-range communications with significantly reduced power consumption. Experimental implementations have shown that LoRaWAN systems can reduce power consumption by 18-20 times compared to Wi-Fi, while also providing encrypted communications [26]. The properties mentioned above make LoRaWAN a well-suited and low-power solution needed for Antarctic devices. These solutions provide low-power communication and adaptive duty-cycling, hence enabling the system to achieve long-term operation in Antarctica.

### 2.5 Marine Sensing Modalities and Deployment Mechanics

The physical implementation of the submersible probe requires careful consideration of three interconnected systems. The sensors that acquire environmental and microbial data, the mechanical systems that enable deployment from a moving vessel, and the waterproof housing that protects sensitive electronics in the harsh Antarctic marine environment. This section reviews the literature across these domains to inform the design of a compact, low-cost, and user-friendly probe suitable for deployment from vessels of opportunity.

### 2.5.1 Microbial Detection Sensors

The selection of sensors for the submersible probe must balance scientific relevance, power consumption, cost, and ease of use. Emma Rocke’s primary interests are oxygen, temperature, salinity, and nutrients, with the ‘added bonus’ of capturing microbial information where possible. The literature reveals two

2.5. Marine Sensing Modalities and Deployment Mechanics

primary approaches for in-situ microbial sensing: optical methods that measure proxies for microbial biomass, and electrochemical methods that detect microbial activity or specific compounds. Optical sensing technologies offer the most mature and field-ready approach. Raimbault and Sanchez Olvera
[27] demonstrated the Openprobe, a low budget probe that integrates conductivity, temperature, depth (Conductivity, Temperature, Depth (CTD)), dissolved oxygen, turbidity, and chlorophyll-a fluorescence. The chlorophyll-a fluorometer uses synchronous detection to reject ambient light which is critical for near surface readings where sunlight penetration is significant and captures the weak fluorescence signals from in-vivo chlorophyll. The oxygen sensor employs an optode based on phase-shift measurement, similar to industry-standard Aanderaa sensors, which provides robust performance without the oxygen consumption issues that plague Clark-type electrodes. Critically, Kühl [28] notes that such oxygen optodes are solid-state sensors that can handle sub-zero temperatures and have been successfully deployed in sea ice environments, directly addressing the Antarctic operational constraint.

The practical path forward, therefore, is to adopt the optical sensing approach demonstrated by the Openprobe. This provides Emma with the core environmental parameters she requires, plus chlorophyll-a as a proxy for phytoplankton biomass which provides valuable insight into microbial community dynamics without the complexity of whole-cell biosensors. The Openprobe’s use of an Adafruit Feather microcontroller and custom Printed Circuit Board (PCB)s demonstrates that such a system can be built with accessible, low-cost components.

### 2.5.2 Tethering and Winch Mechanisms

The deployment of a submersible probe from a moving vessel of opportunity requires careful attention to tether management. Peraud et al. [29] provide a comprehensive analysis of this challenge in their development of a smart tether winch for an Remotely Operated Vehicle (ROV)/Unmanned Surface Vehicle (USV) system. They identify two critical problems with tether systems, namely drag forces that increase with vehicle motion and water current, and entanglement risks that can compromise safety. Their solution is a two-part system consisting of a sensor near the ROV and an intelligent winch on the surface vessel which maintains a small amount of tension in the tether that minimizes both issues. Peraud’s tension module uses toothed wheels to grip the tether with precise speed control via optical encoder feedback, while a separate torque-controlled spooler ensures tidy cable storage. The use of microswitches to detect tether departure angle offers a low-cost method for understanding probe orientation relative to the vessel. Peraud’s work shows the need for tether management while simultaneously highlighting the complexity of achieving it. Their system requires two motors, multiple sensors, and a sophisticated ROS2-based control architecture.

The smart winch literature demonstrates that active tether control is a complex problem requiring significant hardware and software investment. For our system, the tether serves only as a physical connection, with wireless data transfer and recharging occurring upon docking. This allows us to prioritize simplicity implementing a semi-automated winch with the aim of reducing complexity and cost while maintaining safety. This aligns with the vessels of opportunity operational constraints identified by the Ship Observations Team [30] which advise that equipment must be ‘as unobtrusive as possible,’ require minimal ship modifications, and be operable by non-specialists. A straightforward tether management approach ensures that vessel operators can deploy and recover the probe with minimal training, without the burden of maintaining a complex smart winch system.

2.6. Conclusions from Literature Review

### 2.5.3 Waterproofing and Pressure Housings

The protection of electronics in the marine environment, particularly in Antarctic conditions, requires careful material selection and sealing design. The literature provides several validated approaches across different cost and complexity levels. For shallow-water deployments, PVC and 3D-printed housings offer a low-cost entry point. The Openprobe project [27] used a Blue Robotics 2-inch diameter enclosure tube which is rated to significant depths. They also demonstrated the use of Stereolithography (SLA) 3D printing for custom end caps that integrate O-ring grooves, optical ports, and sensor alignment features. The use of stereolithography (SLA) over fused deposition modeling (FDM) is critical because SLA produces fully dense, watertight parts with the dimensional accuracy required for O-ring sealing.

For optical sensors, which form the core of the proposed sensing suite, the waterproofing challenge extends to the optical ports. The Openprobe uses polydimethylsiloxane Polydimethylsiloxane (PDMS), a silicone-based material with good transparency in the visible and near-infrared spectrum, to create optical windows and as a potting compound. The SCINI ROV, developed for under-ice deployment in Antarctica [31], uses an even simpler approach where Light Emitting Diode (LED)s and lasers are cast directly in epoxy resin, creating a solid, waterproof optical assembly without the need for separate pressure housings. This technique has been field-validated to depths of 330 meters in Antarctic waters and represents a robust, low-cost solution for our probe. For sealing, the literature consistently identifies O-rings as the standard method for underwater housings. Proper O-ring groove design, combined with appropriate material selection and hydrophobic grease provides reliable sealing when the housing is assembled correctly. The modular approach used by SCINI, with separate housings for cameras, electronics, and thrusters, simplifies maintenance: if one module fails, it can be replaced without disassembling the entire probe.

### 2.6 Conclusions from Literature Review

The literature demonstrates that successfully designing a marine monitoring system for the Antarctic winter gap requires a delicate balance between robust physical encapsulation, localised data processing, and highly resilient power management. To accommodate deployment from vessels of opportunity, the mechanical design must prioritise simplicity and usability. Rather than employing complex, actively controlled smart winches, a simplified semi-automated tethering mechanism allows non-specialist crews to deploy the submersible probe safely. At the sensor level, optical methodologies, specifically chlorophyll-a fluorometers and phase-shift oxygen optodes, provide the most field-ready approach to gathering critical biological data without the fragility of whole-cell biosensors. These sensors can be effectively protected using SLA 3D-printed housings, O-ring seals, and direct epoxy potting for optical windows.

To survive the extreme thermal operating constraints (-30°C to -1.8°C), the probe’s power and memory systems must diverge from standard commercial architectures. Traditional carbonate-based lithium-ion batteries and NAND flash memory are highly susceptible to capacity fade and charge leakage in freezing conditions. The integration of carboxylate ester-based electrolytes, coupled with passive PCM thermal insulation, ensures reliable power delivery. Furthermore, the use of emerging non-volatile memory technologies, such as MRAM or MEMS-based switches, guarantees that the recorded environmental data remains uncorrupted during prolonged sub-zero deployments.

2.6. Conclusions from Literature Review

Once the probe returns to the surface, the deck-bound docking station serves as a critical edge-computing hub. Classical cloud-centric architectures fail in remote marine environments due to the extreme bandwidth limitations and high latency of satellite communications. By offloading complex processing tasks to the docking station, the system utilises Machine Learning (ML) and Deep Learning (DL) algorithms, such as Convolutional Neural Networks and Isolation Forests, to autonomously filter noisy optical data and detect true ecological anomalies. Consequently, only high-value microbial community shifts are transmitted via satellite, which drastically reduces payload size and preserves system energy.

To bridge the submersible probe and the edge-computing docking station without compromising the waterproof enclosure, NFC has been selected as the short-range data transmission medium for this subsystem. By utilising inductive coupling, NFC offers both data offloading and wireless charging in a fully encapsulated portless form factor. This selection directly addresses the environmental robustness requirements identified in the literature, which eliminates the corrosion and freezing risks associated with exposed electrical contacts. If NFC proves insufficient to meet the system’s data throughput or range requirements under operational conditions, USB-C will serve as a fallback solution, again providing a combined data transfer and charging interface. Ultimately, this synthesised approach yields a secure, power-efficient, and highly autonomous observational pipeline capable of transforming how marine microbiological data is gathered in the world’s harshest environments.

# Chapter 3

# Data Transfer and Visualisation

[Author: Mogamad Saeed Solomon - SLMMOG032]

### 3.1 Introduction

This subsystem deals with the transfer of the stored data on the Antarctic probe to a Local Mission Control Graphical User Interface (GUI) running on a laptop for the data to then be visualized before being sent to the ML processes described in the following chapter. The aim of this subsystem is to provide an accurate, reliable and low-power data communication channel between the probe and laptop, and to implement a User interface (UI) for the researchers to interact with the retrieved data. The subsystem comprises two software components, Backend.py and GUI.py, alongside firmware running on two ESP32-C6 microcontrollers: the submersible probe and a receiver dongle that interfaces with the laptop over USB serial.

### 3.2 Requirement Analysis

When the client, Emma Rocke, was interviewed one of the main points that arose was the need to collect raw data samples to do post-processing at a later stage. To meet this requirement, large volumes of raw data need to be accurately and reliably transferred between the two parts of the system while adhering to the battery limitations of prolonging the system lifespan. Due to the extreme environmental conditions of the Antarctic, a fully encapsulated solution is required, alluding to the need for wireless communication between the two parts of the system. Aside from purely visualizing the data, because researchers or civilians will be operating the system it needs to be intuitive and easy to interact with, control, and monitor. As such, the requirements for this subsystem are listed below in Tables 3.1 and 3.2.

3.2. Requirement Analysis

### 3.2.1 Functional Requirements

Table 3.1: System Functional Requirements

ID | Requirement | Description
FR1 | Quality | The data transfer needs to be accurate, fast and reliable
FR2 | Wireless transfer | Data transfer from probe to laptop needs to be wireless
FR3 | Error checking | No corruption of data during transfer needs to be implemented
FR4 | Save/Load data | Functionality to save current data or load previous data
FR5 | Wake-up | The probe needs to wake up from deep sleep to enable its antennae for advertising and vice versa
FR6 | Offline | The transfer protocol and GUI needs to be able to function without any internet connection

### 3.2.2 User Requirements

Table 3.2: System User Requirements

ID | Requirement | Description
UR1 | GUI | Interactive GUI for users to visualize the retrieved data on the receiver end (Laptop/Host).
UR2 | Probe setup | Easy, intuitive control interface for the probe to control its mode of operation (e.g., Prepare Dive vs. Data Offload).
UR3 | Battery indicator | A means to determine the remaining probe battery life to prevent sce-narios where the probe could potentially fail mid-exploration.
UR4 | Data display | Display raw data retrieved from the exploration in both a raw format and a more intuitive way (such as via graphs or charts).

### 3.2.3 Specification Analaysis

Table 3.3: Specification analysis

ID | Specification | Description
SP01 | Wake-advertising time | The submersible probe needs to wake from deep sleep to advertise its signal in < 10s
SP02 | Data transfer window | The complete data transfer process needs to be < 1min
SP03 | Data integrity | Transferred data accuracy > 95%
SP04 | GUI record update time | The time taken to update the display upon receival of a record needs to be < 1s to prevent lag
SP05 | Battery indicator | A battery level status indicator needs to be visible on the GUI for clients to be aware of the probe remaining battery lifespan

3.3. Acceptance Test Procedures

### 3.2.4 Traceability Matrix

Table 4.4 maps each requirement to the design decisions and ATPs that address it.

Table 3.4: Traceability Matrix

Requirement | Specification | Acceptance Test Procedure (ATP)
FR1 | SP04 | ATP06
FR2 | SP02 | ATP01
FR3 | SP03 | ATP02
FR4 | | ATP04
FR5 | SP01 | ATP03
FR6 | SP04 | ATP05
UR1 | SP04 | ATP04, ATP06
UR2
UR3 | SP05 | ATP07
UR4 | SP02, SP04 | ATP04

### 3.3 Acceptance Test Procedures

The ATPs section outlines the tests to be conducted on the final design alongside their acceptance criteria to determine whether the specifications based on the requirements have been met.

Table 3.5: ATP for the Data Transfer and Visualisation subsystem

ID | Specification Description | Acceptance Criteria
ATP01 | Wireless recovery | Transfer distance between sender and re-ceiver at least 10 m
ATP02 | Data integrity > 95% | Data records accurately transferred with a final error margin < 5%
ATP03 | Initiate transfer on wake-up in under 10 s | When the probe wakes from deep sleep the transfer protocol must be initialised in under 10 s and safely de-initialised before returning to sleep
ATP04 | Data visualisation | Raw data received from probe/loaded able to be displayed on GUI
ATP05 | Fully offline operation | Both the transfer protocol and GUI are able to be operated without any internet connection
ATP06 | GUI response rate | GUI tables/graphs updated in less than a second for seamlessness
ATP07 | Battery display | GUI indicates the remaining probe battery life

3.4. Design Choices

### 3.4 Design Choices

### 3.4.1 Block Diagram

Raw data is collected from the sensors of a submersible probe deployed overboard a vessel of opportunity and stored locally on the probe for the duration of the mission. Once retrieved, the probe initiates a wireless transfer process to send the raw data from its onboard storage to the receiver system, where post-processing and data viewing take place (FR2, UR1, UR4). A simplified overview is shown in Figure 3.1.

Figure 3.1: Simplified block diagram of flow of data throughout solution


### 3.4.2 Transfer Protocol Selection

Three wireless protocols were evaluated over the course of the project. The figures of merit used for comparison were range, power consumption, implementation cost, and suitability for use in the Antarctic marine environment.

Option 1: NFC

The initial design centred around a bipartite system comprising the submersible probe and a docking station for data offloading and charging. NFC was considered primarily because it allowed the probe to be entirely portless. The same 13.56 MHz coil could theoretically service both data transfer and inductive wireless charging, eliminating every penetration point in the enclosure and removing the primary ingress risk in a cold saltwater environment. At 424 kbit/s (NFC High Speed), the anticipated data volume of well under 1 MB per dive could be transferred in a few seconds.

However, this approach was ruled out for three reasons: integrated NFC wireless charging listener ICs (e.g. Renesas PTX30W [32]) were far too complex and expensive for the project budget; the docking station was descoped since vessels of opportunity may lack the means to power it; and the NFC protocol’s strict proximity and orientation requirements are poorly suited to use on the open ocean.

3.4. Design Choices

Option 2: Bluetooth Low Energy (BLE)

BLE was the natural successor candidate. The ESP32-C6 includes a native BLE radio, incurring no additional hardware cost. BLE offered substantially higher data rates than NFC (up to 2 Mbit/s in BLE 5.0) and greater tolerance for device misalignment. A GATT server profile was fully designed and implemented on the probe, exposing four characteristics: METADATA (probe identity), CONTROL (operational state commands), DATA (transfer payload), and STATUS (real-time health monitoring). CRC-16 packet validation and GPIO-based reed switch deep sleep wakeup were also implemented at this stage.

Despite a complete firmware implementation, BLE failed during hardware validation. The probe’s BLE advertising was undetectable by both a smartphone running nRF Connect and a laptop running a Python GATT server, across both available ESP32-C6 development boards. Reversing the setup by making the laptop act as the server did not resolve the issue. Given that the problem manifested identically on both boards, the root cause was attributed to immaturity in the ESP32-C6 BLE stack, necessitating a more reliable alternative.

Option 3: ESP-NOW (Selected)

ESP-NOW is a connectionless protocol developed by Espressif that operates at the Data Link layer, reducing the five layer OSI model to one [33]. It is native to the ESP32-C6, requires a second ESP32 as a receiver dongle as its only additional cost, and proved immediately functional where BLE had failed. Table 3.6 summarises the full comparison across all three protocols.

Table 3.6: Wireless Protocol Comparison

Protocol | Range | Power | Data Rate | Cost | Notes
ESP-NOW | ∼100 m | Ultra-low | 1 Mbit/s | R230 (2x ESP32) | Data-link layer operation; minimal stack overhead; na-tive to ESP32-C6 [33]. Se-lected.
BLE | <10 m | Low | 2 Mbit/s | R115 (ESP32) | Fully implemented; aban-doned due to hardware-level advertising failure on both ESP32-C6 boards.
NFC | <0.2 m | Low | 424 kbit/s | R508 (ESP32, NFC receiver and dynamic tag)[34, 35] | Strict orientation require-ments unsuitable for ma-rine use; docking station de-scoped.

ESP-NOW was selected on the basis of proven hardware reliability, the lowest effective implementation cost at R230, a range far exceeding the ATP01 requirement of 10 m, and ultra-low power consumption consistent with the probe’s battery constraints.

3.5. Final Design

### 3.4.3 GUI Architecture

The Mission Control GUI was designed in Python using the CustomTkinter framework, with matplotlib embedded for graphing. Python was chosen for two reasons: the ML anomaly detection models in Subsystem 2 are also implemented in Python, enabling direct integration without an inter-process boundary; and PySerial provides straightforward cross-platform serial communication without driver dependencies beyond the USB CDC stack built into the ESP32-C6.

The GUI was architected as two decoupled modules: Backend.py handles all serial I/O, packet parsing, and ML evaluation, while GUI.py provides the interface layer and calls backend functions through a thread-helper pattern (run_async for async coroutines, run_in_thread for blocking I/O) to prevent the GUI from freezing during transfers. This separation made it possible to unit-test the backend independently using simulated data and allowed easier management of the growing codebase.

The initial GUI design is shown in Figure 3.2, highlighting the key elements that address the user requirements:

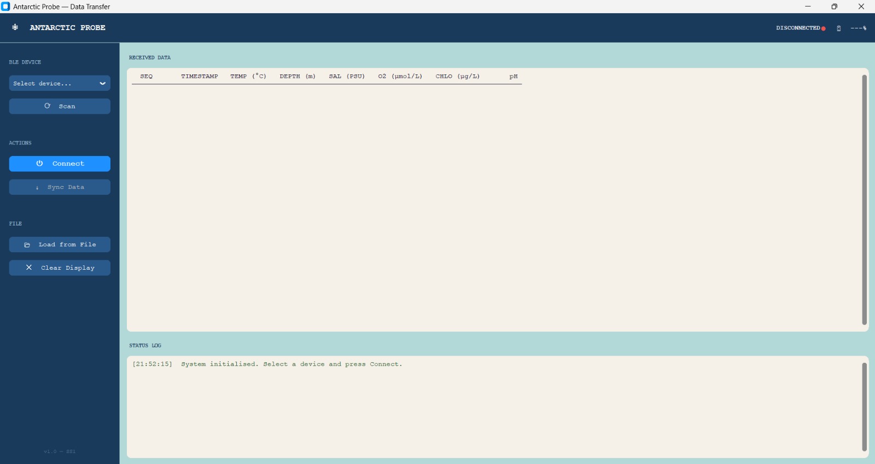
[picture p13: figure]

Figure 3.2: Initial GUI design

- Top panel indicating current probe status and battery level (UR3, SP04)
- Side toolbar for intuitive probe control (UR2)
- Display area for incoming raw data (UR4)
- Save/Load file functionality (FR4)
- Status terminal for task execution feedback (UR5)

### 3.5 Final Design

### 3.5.1 Probe Command-Controlled Structure

The probe wakes on a reed switch interrupt, initialises the WiFi radio in station mode, and calls ESPNOW_Init() to register the dongle’s MAC address as a peer (FR5). It then waits for commands sent by the GUI via the dongle over ESP-NOW. The four supported commands are:

3.5. Final Design
- [CMD]:CONNECT — Verifies communication between probe and dongle and updates the probe’s remaining battery level on the GUI
- [CMD]:DISCONNECT — De-initialises ESP-NOW on the probe to conserve battery
- [CMD]:PREPARE — Resets the probe’s memory and stores the current date and time in the session header, providing a timestamp reference for each record (since the probe cannot track time during deep sleep)
- [CMD]:RETRIEVE — Initiates the data offloading process for all records logged during the mission

The full command-controlled state flow is shown in Figure 3.3.

On the dongle side, Receiver_Dongle.ino implements a three-state machine (IDLE, READY, CONNECTED) controlled via a serial command protocol from the laptop. On boot, the dongle prints a heartbeat message allowing the Python backend to locate the correct COM port automatically. The backend then sends CMD:STOP_HEARTBEAT. When the connect button is pushed by the user a CMD:CONNECT is issued which initialises ESP-NOW and registers the probe as a peer. When CMD:RETRIEVE is issued, the dongle arms itself and forwards validated records to the laptop as DATA: CSV lines, consumed by Backend.py’s

sync_probe() function.

Figure 3.3: Stateflow chart of the command-controlled flow of the submersible probe


3.5. Final Design

### 3.5.2 Wire Format: data_packet.h

All packet definitions are centralised in data_packet.h, included by both the probe firmware (espnow_transfer.cpp) and the receiver dongle firmware. The shared header uses packed structs to ensure an identical binary
layout on both ESP32 targets. Static assertions verify struct sizes at compile time (SessionHeader_t:
16 bytes; ProbeRecord_t: 62 bytes), catching layout regressions if field types are changed. This comfortably falls within the 250-byte maximum payload of ESP-NOW.

One record is transferred per message to keep error-checking straightforward and to allow additional sensor fields to be appended in future without redesigning the framing layer. The record structure is detailed in Table 3.7.

Table 3.7: Probe Record Packet Structure (62 bytes, little-endian)

Byte Offset | Type | Field | Description
[0] | uint8 | pkt_type | Always PKT_TYPE_RECORD (0xA1)
[1:5] | uint32 | entry_num | Record index (0-based)
[5:9] | uint32 | ms_since_start | Milliseconds since session_start_ms
[9:13] | float32 | temperature_c | Temperature (°C)
[13:17] | float32 | pressure_dbar | Pressure (dbar)
[17:21] | float32 | spec1 | Spectrometer channel 1
[21:25] | float32 | spec2 | Spectrometer channel 2
[25:29] | float32 | spec3 | Spectrometer channel 3
[29:33] | float32 | spec4 | Spectrometer channel 4
[33:37] | float32 | spec5 | Spectrometer channel 5
[37:41] | float32 | spec6 | Spectrometer channel 6 (excitation)
[41:45] | float32 | spec7 | Spectrometer channel 7 (fluorescence)
[45:49] | float32 | spec8 | Spectrometer channel 8
[49:53] | float32 | spec9 | Spectrometer channel 9
[53:57] | float32 | spec10 | Spectrometer channel 10
[57:61] | float32 | spec11 | Spectrometer channel 11
[61] | uint8 | checksum | XOR of bytes [0:61]

All multi-byte fields are little-endian, matching the native byte order of both the ESP32 (RISC-V based) and the x64 laptop. Chlorophyll-A concentration is deliberately excluded from the on-wire format: the probe transmits raw excitation_raw and fluorescence_raw ADC counts, and the conversion to concentration is performed by Subsystem 2’s ML processing step. This is to prioritise raw data collection and prevent power drain by performing computation on the probe.

The final byte is an XOR checksum computed over all preceding bytes (FR3), chosen as a lightweight integrity check that avoids per-record traffic overhead. A failed record is reattempted at most 3 times at 500 ms intervals; records that still fail are discarded and appear as empty entries in the raw data display.

3.5. Final Design

### 3.5.3 Mission Control GUI

The GUI is a standalone Python desktop application (GUI.py) that runs without internet connectivity (FR6). It is structured around a top toolbar, a sidebar of controls, a tabbed main panel, and a persistent status log. The application state machine mirrors the dongle’s: buttons are disabled until the dongle is detected, probe controls are then unlocked, and data-retrieval functions are enabled only once a probe connection is confirmed. The final design is shown in Figures 3.4 and 3.5.

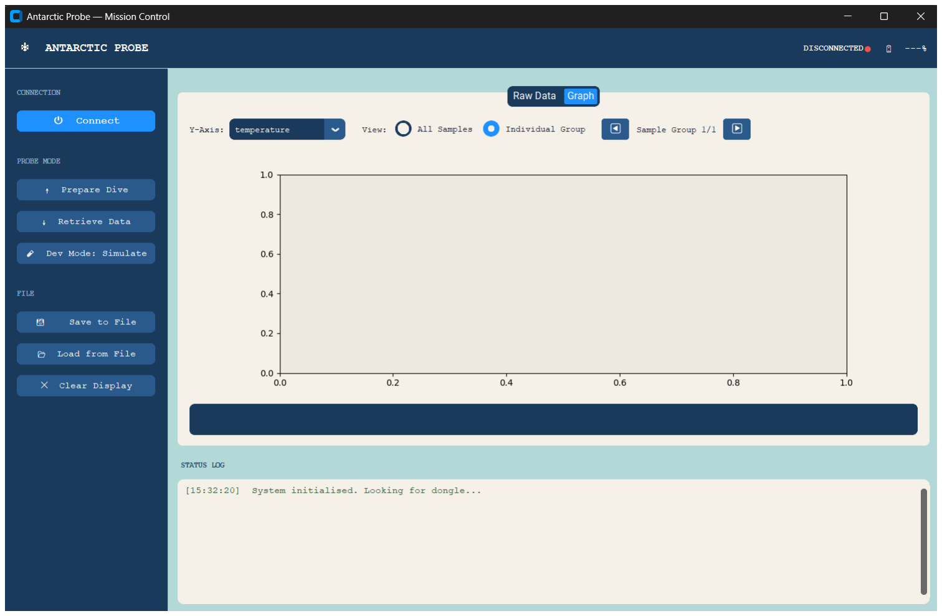
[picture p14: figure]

Figure 3.4: Final GUI design: Raw Data tab | Figure 3.5: Final GUI design: Graph tab

Sidebar Controls

The sidebar is divided into three sections. The Connection section contains the Connect/Disconnect button, which triggers the dongle discovery routine and, on success, the probe pairing sequence. The Probe Mode section provides three action buttons: Prepare Dive, which sends PREPARE; Retrieve Data, which sends RETRIEVE; and Dev Mode: Simulate, which injects synthetically generated records directly into the GUI at the same rate and in the same format as a live retrieval, without requiring a physical probe or dongle. This served as the primary simulation submodule for validating the full GUI pipeline. This included live table updates, graph rendering, and anomaly flagging independently of hardware availability. The File section provides Save to File (CSV export), Load from File (CSV import), and Clear Display (FR4).

Raw Data Tab

The Raw Data tab displays records in a fixed-width monospaced table with columns for all fields in the transfer protocol. Records are appended live as they arrive; anomalous records are flagged inline with an [ANOMALY] marker produced by the MarineAnomalyDetector from Subsystem 2. The text widget is read-only to prevent accidental modification.

Graph Tab

The Graph tab provides a visual view of trends in the sensor data. A dropdown selects the y-axis variable (temperature, pressure, excitation, and so forth), with the x-axis fixed to elapsed time in milliseconds. Two view modes are available:

- All Samples — plots the complete dataset as a connected line series.

3.6. Testing and Results
- Individual Group — divides the dataset into groups of 15 readings (configurable via SAM-PLES_PER_GROUP) and allows the researcher to step through groups with previous/next buttons, enabling closer inspection of short time windows.

The graph updates automatically on y-axis or mode changes and refreshes incrementally as new records arrive during a live retrieval. Screenshots of the GUI displaying simulated data in both the raw data and graph views, including a dataset with injected anomalies, are provided in Appendix A.

### 3.5.4 Backend: Serial Protocol and Data Flow

Backend.py manages the shared serial port and exposes a clean async/sync API to the GUI. On startup it scans all COM ports, reads up to five lines from each, and confirms the correct port by matching the DONGLE_READY_MSG string, making discovery automatic regardless of which USB port the dongle occupies. The sync_probe() function reads DATA: lines in a blocking loop, evaluates each record for anomalies via the MarineAnomalyDetector, and delivers results to the GUI’s on_record callback in real time. The loop terminates on a [SESSION] EOF marker from the dongle.

### 3.5.5 Software Prerequisites and Execution

The GUI requires Python 3.10 or later. The following third-party libraries must be installed prior to first use. With an active internet connection, all dependencies can be installed in a single terminal command:

pip install pyserial customtkinter matplotlib

Once installed, the application is launched from a terminal in the directory containing GUI.py:

python GUI.py

No Integrated Development Environment (IDE) is required. After launch, no further internet access is needed and the application operates fully offline (FR6). The receiver dongle must be plugged in via USB before pressing Connect, after which the GUI will locate the correct COM port automatically.

### 3.6 Testing and Results

### 3.6.1 Testing Procedures

Due to the black-box testing mandate and the May 18th deadline, each component of the subsystem was tested independently before integration testing was attempted. Where hardware-in-the-loop testing was performed, each test was repeated across at least three independent runs and the results averaged to account for timing variability.

The end-to-end data transfer pipeline was verified by issuing a CMD:RETRIEVE command from the GUI to a connected dongle, which in turn relayed the command to the probe over ESP-NOW. The probe responded by transmitting synthetically generated records, constructed to match the ProbeRecord_t structure exactly, back through the dongle to the laptop. The transfer protocol was tested with 5 synthetic datasets with 100 entries. Each record was validated by data_packet.h against its XOR

3.6. Testing and Results

checksum on the receiver side before being passed to the GUI for display, confirming that the full transfer path from probe firmware through to GUI rendering functioned correctly end-to-end.

Table 3.8: ATP Results

ID | Test Method | Result
ATP01 | Sender and receiver distance was incrementally increased in 5 m steps. Connect, prepare, and re-trieve were each tested at each distance across 3 runs. | PASS. All modes of operation confirmed working at all distances tested. Maxi-mum reliable range was 20 m with obstacles (walls and trees) and 30 m unobstructed.
ATP02 | Five datasets of 100 records each were transferred between probe and dongle. Received records were compared against the trans-mitted set. | PASS. Average error margin of 1.2% across all datasets, well below the 5% target. Records exceeding 3 send attempts were successfully discarded and logged.
ATP03 | Time from deep sleep wake-up to first ESP-NOW advertisement was measured using serial times-tamps, averaged over 5 iterations. | PASS. Average wake-up to advertising time was 8s s falling within the 10 s target.
ATP04 | Simulated and received data was displayed in both the raw data and graph tabs. Anomaly detection was verified by in-jecting records flagged by the MarineAnomalyDetector. | PASS. GUI displayed all records and up-dated seamlessly as they arrived. Anoma-lous records were correctly flagged. No lag or freezing observed across all tests.
ATP05 | Application executed with the laptop in airplane mode to ver-ify no internet dependency. | PASS. Standalone Python application and transfer protocol functioned correctly. Both probe and dongle confirmed discon-nected from any WiFi network.
ATP06 | Timing functions were added in the debug process to measure the duration from receiving the data to displaying it. GUI was inter-acted with mid transfer to ensure no blocking. | PASS. No blocking observed while interact-ing with the GUI. The time from receiving data to displaying it was measured to av-erage around 864ms.
ATP07 | Battery indicator in top toolbar of GUI updated to reflect probe battery status. | PASS. Immediately upon receiving ac-knowledgement of connection from probe the GUI monitored the serial channel for the battery level message sent over the transfer protocol. The battery level indi-cator was then updated.

3.7. Recommendations

### 3.7 Recommendations

For future work, two improvements are recommended. First, once the ESP32-C6 BLE stack matures, migrating back to BLE would eliminate the requirement for a separate dongle, reducing system cost and complexity. Secondly, the current ESP-NOW transfer is unencrypted; adding the protocol’s built-in CCMP encryption layer would protect the integrity of the scientific data against interception in shared RF environments.

### 3.8 Conclusion

This chapter presented the design, implementation, and testing of the Data Transfer and Visualisation subsystem for the Antarctic Probe. ESP-NOW was selected as the data transfer protocol based on its ultra-low power consumption, communication range, and hardware reliability — attributes that the evaluated alternatives could not collectively satisfy. Should the ESP32-C6 BLE stack mature and stabilise, migrating to BLE remains a recommended future direction given its lower system cost and reduced architectural complexity.

The Mission Control GUI was implemented as a standalone, offline Python application fulfilling all user-facing requirements: probe control (UR2), battery status indication (UR3), a live data table with anomaly flagging (UR4) and a trend visualisation via a dedicated graph tab (UR1). The decoupled Backend.py/GUI.py architecture maintains interface responsiveness during blocking I/O operations while simplifying independent unit testing, satisfying FR6.

# Chapter 4

# Edge Architecture and Explainable AI

### 4.1 Introduction

The Antarctic marine environment presents an unparalleled operational challenge known as the “winter data gap‘. During the austral winter, extreme sea ice coverage isolates substantial portions of the Southern Ocean, rendering conventional surface vessel sampling operations physically impossible for several consecutive months. This geographical and temporal isolation necessitates the deployment of autonomous, submersible sensing platforms capable of operating independently beneath the ice.

Subsystem 2 (SS2) of the Antarctic Probe project was engineered specifically to address this paradigm. As a submersible operates in an aquatic environment entirely devoid of conventional communication bandwidths (such as cellular or high-speed radio frequency networks), the real-time transmission of high-fidelity spectral data to researchers is physically precluded. Consequently, a paradigm shift towards Edge Computing is mandated [?]. By processing and storing data locally at the “edge’ of the network, autonomous underwater systems can circumvent severe bandwidth and latency bottlenecks [?]. SS2 establishes this critical bridge between the raw, high-dimensional photometric data acquired by the physical sensor suite (Subsystem 4) and the localized Mission Control graphical user interface (Subsystem 1). This is achieved through the implementation of a highly power-efficient, multi-state firmware architecture for non-volatile local storage, followed by the rigorous application of deterministic Explainable Artificial Intelligence (XAI) models upon retrieval.

### 4.2 Requirements and Specifications

To ensure that the edge architecture and machine learning pipeline are strictly aligned with the overarching constraints of a harsh Antarctic deployment, a rigorous set of requirements and specifications was established. These parameters dictate the system’s power consumption limits, operational autonomy, and computational efficacy.

### 4.2.1 User Requirements

User Requirements (UR) represent the qualitative, mission-critical needs of the marine biologists and oceanographers interacting with the probe.

4.3. Traceability Matrix

Table 4.1: Subsystem 2 User Requirements |c|p4cm|X|
ID Requirement Title Description UR2.1 Reliable Offline Storage The system must reliably store sensor readings offline over an extended deployment period without data loss due to battery depletion or unexpected system resets. UR2.2 Actionable Biological Insights The system must provide non-specialist researchers with immediately actionable, understandable biological insights upon retrieval, avoiding ambiguous or generic binary anomaly flags.

### 4.2.2 Functional & System Requirements

System Requirements (SR) formalize the qualitative user needs into tangible, functional operational mandates for the engineering design.

Table 4.2: Subsystem 2 Functional and System Requirements |c|p4cm|X|
ID Requirement Title Description SR2.1 Non-Volatile Storage Management The probe must implement non-volatile storage capable of preserving complex data structures across deep sleep cycles with minimal active duty cycling. SR2.2 Multi-State Deployment Lifecycle The firmware must manage a deterministic multi-state deployment lifecycle to prevent the acquisition of polluted surface-level data during the probe’s descent. SR2.3 Offline Machine Learning Evaluation The localized machine learning evaluation pipeline must be capable of rapidly processing telemetry completely offline, eliminating reliance on cloud infrastructure.

### 4.2.3 System Specifications

System Specifications quantitatively constrain the engineering design, providing exact metrics against which the subsystem can be empirically validated.

Table 4.3: Subsystem 2 System Specifications |c|p3.5cm|X|
ID Specification Title Quantitative Metric Spec1 Quiescent Current Overhead The system’s non-volatile memory management and deep sleep state must be optimized to draw an absolute minimum quiescent current, structurally remaining below 20 µA to preserve the primary battery. Spec2 Fixed MTU Payload The acquired sensor data must be strictly formatted into a 14-value structure, resulting in a fixed Maximum Transmission Unit (MTU) payload of precisely 58 bytes per reading, avoiding dynamic memory allocation overhead. Spec3 ML Inference Speed The machine learning anomaly classification engine running on the Mission Control interface must execute a full inference cycle in under 2.0 seconds per record.

### 4.3 Traceability Matrix

To mathematically guarantee that every engineering specification directly serves a foundational user requirement, the Traceability Matrix maps the design topology from the user’s initial need through to the empirical testing procedure.

4.4. Acceptance Test Procedures (ATPs)

Table 4.4: Requirements Traceability Matrix mapping URs to System Specifications and ATPs

User Require-ment (UR) | System Require-ment (SR) | Specification (Spec) | Test Procedure (ATP)
2*UR2.1 (Offline Storage) | SR2.1 (Non-Volatile Mgt) | Spec1 (Quiescent Current) | ATP-02
| SR2.2 (Multi-State Lifecycle) | Spec2 (Fixed MTU Payload) | ATP-01
2*UR2.2 (Action-able Insights) | 2*SR2.3 (Offline ML Evaluation) | Spec3 (Inference Speed < 2.0s) | ATP-04
| | N/A | ATP-03

### 4.4 Acceptance Test Procedures (ATPs)

The Acceptance Test Procedures define the explicit, empirical methodologies utilized to validate the subsystem against the constraints outlined in the Traceability Matrix. The empirical results of these tests are presented in the final validation section of this chapter.

Table 4.5: Acceptance Test Procedures Definition for Subsystem 2 |c|c|p4.5cm|X|
Test ID Trace Test Procedure Expected Outcome ATP-01 SR2.2 Hardware-in-the-Loop (HITL) State Machine Validation: Trigger hardware interrupts on the microcontroller and monitor the state progression via serial telemetry. The firmware perfectly executes the required deployment states (including sinking delays) without relying on power-intensive blocking delay() calls. ATP-02 SR2.1, Spec1 RTC Memory Persistence across Deep Sleep: Induce consecutive deep sleep resets during the active logging phase and subsequently read the designated memory blocks. Data structures are fully preserved across sleep cycles without corruption or volatile memory loss. ATP-03 UR2.2 XAI Biological Classification Accuracy: Inject a dataset containing predefined, physical-threshold biological anomalies (Phytoplankton, Cyanobacteria, CDOM) into the analytical pipeline. The XAI engine reliably detects and outputs the exact, explicit biological string classification for each specific spectral signature with zero false positives. ATP-04 SR2.3, Spec3 Edge ML Inference Speed: Pipe raw 14-value sensor strings into the Python inference engine and utilize temporal profiling libraries to measure execution latency. The end-to-end evaluation of the Isolation Forest and XAI deterministic ruleset executes comprehensively in under 2.0 seconds.

### 4.5 Design Choices

The extreme environmental constraints of the Antarctic deployment—specifically the strict battery limitations and complete lack of off-grid computing infrastructure—necessitated rigorous trade-off analyses for both the hardware storage media and the software analytics paradigms.

4.5. Design Choices

### 4.5.1 Onboard Memory Architecture

The requirement to securely store data for extended periods utilizing less than 20 µA of quiescent current prompted an extensive evaluation of onboard memory topologies. The two primary candidates considered were conventional NAND Flash (or MicroSD cards) and Ferroelectric RAM (F-RAM).

Conventional Flash memory relies on trapping electrons within a floating gate mechanism. Programming (writing) or erasing data requires inducing Fowler-Nordheim tunnelling of electrons across a dielectric oxide layer. This physical process inherently demands high programming voltages, typically exceeding 10V, which must be generated from the system’s standard 3.3V logic rail utilizing an internal charge pump [?]. This charge pump introduces substantial current spikes (often reaching tens of milliamperes) and high temporal latency during write operations, severely violating the strict power budgets required for deep-sleep duty cycling. Furthermore, the repeated electron tunnelling irreparably degrades the oxide layer, limiting Flash endurance to approximately 10⁵ write cycles.

In contrast, F-RAM utilizes a lead zirconate titanate (PZT) film. Data is stored by applying a brief electric field to shift the central zirconium/titanium atom within the crystal lattice, thereby changing the crystal’s polarization state [?]. Because this process relies on molecular displacement rather than forced electron tunnelling, it requires no high-voltage charge pump. F-RAM writes data at native logic-level voltages with near-zero delay (often in the nanosecond range) and draws practically negligible write currents (in the microampere range). This physical mechanism yields virtually infinite read/write endurance (typically 10¹⁴ cycles).

F-RAM is therefore unequivocally the superior architecture for subsea IoT devices. Crucially, however, due to severe global component procurement delays during the project timeline, the physical F-RAM chip was unavailable for immediate integration. To circumvent this, the ESP32-C6’s internal RTC SRAM (which similarly survives deep sleep with micro-amp overhead) was utilized to mathematically and functionally simulate the F-RAM behaviour for successful Hardware-in-the-Loop (HITL) physical testing.

Table 4.6: Figures of Merit: MicroSD/Flash vs. F-RAM Architecture |X|X|X|X| Figure of Merit MicroSD / NAND Flash F-RAM Winner Write Current High (∼ 30 mA) Ultra-Low (∼ 100 µA) F-RAM Write Speed High Latency (ms) Instantaneous (ns) F-RAM Write Endurance Limited (10⁵

cycles) Virtually Infinite (10¹⁴ cycles) F-RAM

Integration Complexity High (FAT32/SPI overhead) Low (Direct bus/SPI) F-RAM

### 4.5.2 Anomaly Detection Algorithms

To achieve offline, localized anomaly detection on the Mission Control laptop (SR2.3, UR2.2), various machine learning paradigms were assessed. The primary trade-off lay between Deep Neural Networks (DNNs) and statistical isolation methods.

Deep Neural Networks (such as Autoencoders or Convolutional layers) are highly capable of modelling complex non-linear relationships. However, they fail critically in edge environments. DNNs demand

4.6. Submodule Design and Implementation

massive matrix multiplications and possess immense memory footprints, heavily taxing the computational overhead of standard laptops [?]. Furthermore, DNNs inherently act as “black boxes”; they provide a generalized anomaly score or binary flag but offer zero scientific transparency regarding the causal factors. This complete lack of explainability directly violates UR2.2, rendering them entirely unsuitable for researchers attempting to decipher specific marine biological events.

An Isolation Forest algorithm was selected as the optimal statistical baseline. Unlike standard models that attempt to profile “normal” behaviour, Isolation Forests identify anomalies by explicitly partitioning data via random decision trees [?]. Because anomalies are statistically few and distinct, they are isolated closer to the root of the decision trees. This approach operates at a highly efficient O(n log n) time complexity, allowing instantaneous offline inference on a standard laptop. To fulfill the scientific explainability constraint (UR2.2), the Isolation Forest was augmented with a post-hoc Deterministic Explainable AI (XAI) ruleset. If the statistical model flags an anomaly, the XAI ruleset mathematically evaluates the payload against established biological spectral signatures. This dual-layered approach provides the perfect balance of statistical computational efficiency and rigorous biological clarity.

Table 4.7: Figures of Merit: DNN vs. Isolation Forest + XAI |X|X|X|X| Figure of Merit Deep Neural Networks Isolation Forest + XAI Winner Computational Overhead Very High (O(n

2
) / GB memory) Low (O(n log n) / MB memory) Isolation Forest
Training Data Required Massive (Thousands of epochs) Moderate (Small batch trees) Isolation Forest
Inference Latency High (Requires GPU accel.) Instantaneous (CPU friendly) Isolation Forest Scientific Explainability Black Box (No causal insight) Transparent (Deterministic) Isolation Forest

### 4.6 Submodule Design and Implementation

The edge architecture is divided into an onboard physical hardware layer running low-level state automation, and an offboard software execution layer handling localized statistical inference and explainable classification.

### 4.6.1 Onboard Firmware State Machine and Mission Lifecycle

The deterministic multi-state deployment lifecycle is executed by the RISC-V core of the FireBeetle 2 ESP32-C6. To absolutely minimize quiescent current draw, the architecture leverages the ESP32’s deep sleep mode. State transitions are made persistent across deep sleep resets without power overhead by mapping critical tracking variables to the Real-Time Clock (RTC) fast memory domain utilizing the RTC_DATA_ATTR macro attribute.

The firmware lifecycle is strictly segregated into four operational states:

1. STATE_STANDBY: An indefinite deep sleep state representing the probe’s pre-deployment phase. The internal hardware timer wakeup module is systematically unmasked, and the system relies entirely on an external wake-up source. This is linked via the esp_sleep_enable_ext1_wakeup()

4.6. Submodule Design and Implementation

API to the low-power I/O domain (LP-IO), awaiting physical activation via a magnetic reed switch without actively polling.

2. STATE_ARMED: The sinking delay phase. This is parameterized to 15 seconds for accelerated Hardware-in-the-Loop (HITL) debugging and 15 minutes for physical maritime deployment. Upon triggering, the system boots, prints arming diagnostics, configures a software-assisted sleep timestamp utilizing esp_sleep_enable_timer_wakeup(), and immediately returns to deep sleep. This phase allows the mechanical winch assembly to lower the probe to the target operational depth, strictly preventing the pollution of the F-RAM memory block with surface or deck telemetry.
3. STATE_LOGGING: The active sensor polling loop. The microcontroller awakens via the internal hardware timer interrupt. It sequentially samples the 14 environmental and optical variables from Subsystem 4, structures the binary payload, increments the absolute record index, writes the payload to the simulated F-RAM array, and re-enters deep sleep within a highly optimised active duty cycle.
4. STATE_OFFLOAD: Triggered by a second manual GPIO low interrupt during an active logging cycle. The state machine halts deep sleep scheduling and initialises the ESP-NOW communication link layer via Subsystem 1. The firmware sequentially flushes the non-volatile memory block into the transmission array buffer and gracefully resets the state machine logic back to STATE_STANDBY.

Figure 4.1: Figure: 4-State Mission Lifecycle and Power-Gated State Transitions

### 4.6.2 Data Structure Contract and the 11-Step Spectrometer PWM Ramp

To guarantee seamless data continuity across the onboard memory buffer and the ESP-NOW transmission layer, a strict binary wire format was defined. The ProbeRecord_t structure strictly occupies 58 bytes. Data padding was aggressively eliminated by packing the struct sequentially utilizing the GCC

__attribute__((packed)) directive.

The structure consists of:

- Two uint32_t blocks for metadata (the monotonically increasing Sequence ID and elapsed timestamp in milliseconds).
- A 2-element float block for environmental variables (DS18B20 temperature and the analogue depth conversion).
- A 10-element float block specifically designed to hold the raw AS7341 spectral values (F1415 through to the Near-Infrared NIR channel).

The temporal design of the optical acquisition loop ensures high-fidelity particulate modeling. A single complete measurement cycle spans 11 discrete rows of data generated across an automated LED Pulse-Width Modulation (PWM) ramp (Step 0 to Step 10). As the Blue excitation LED (F2445) climbs linearly in intensity, the system captures the subsequent exponential rise of target fluorescent emissions. This feeds the inference engine an enriched temporal curve rather than a flat, static baseline.

4.7. Testing and Validation

### 4.6.3 Localised Explainable AI (XAI) Classification Engine

The offboard processing pipeline is embedded within the CustomTkinter graphical user interface (GUI). Incoming 14-column packets received over the USB-CDC serial port are passed asynchronously to an instantiated MarineAnomalyDetector class. The multidimensional data vector is isolated via the trained Isolation Forest model based on anomalous path-length differences in the decision trees.

To transcend the standard black-box paradigm of statistical machine learning, the system inserts a post-hoc deterministic classification layer directly after the Isolation Forest filter. If an anomaly is definitively identified, the engine computes specialised slope and amplitude ratio vectors against the baseline blue excitation channel (F2445). Three biological filter thresholds were mathematically calibrated from physical bench tests to prevent false negatives.

Phytoplankton Bloom (Chlorophyll-a): Triggered when F8680

F2445

> 0.075

(4.1)

Cyanobacteria Population Shift (Phycoerythrin): Triggered when F5555 + F6590

F2445

> 0.08

(4.2)

Colored Dissolved Organic Matter (CDOM Decay): Triggered when F1415 + F3480

F2445

> 0.08

(4.3)

If an anomaly mathematically fails to trigger any of the aforementioned biological filters, the engine definitively outputs “Non-Biological Variance / Sensor Artifact”.

Figure 4.2: Figure: Comprehensive Architectural Decision Tree of the Multi-Layered Isolation Forest and Calibrated XAI Ruleset

### 4.7 Testing and Validation

The operational integrity of the edge data architecture and the localised machine learning pipeline was rigorously validated through empirical Hardware-in-the-Loop (HITL) physical testing and software-inthe-loop simulation runs. This validation strictly adhered to the constraints of the Acceptance Test Procedures (ATPs) defined in Section 3.

4.7. Testing and Validation

Table 4.8: Summary of Acceptance Test Procedure (ATP) Results l X l l r Test ID Target Specification Measured Parameter Pass Criteria Status ATP-01 SR2.2: State Transitions Wakeup Cause Evaluation Zero Loop Hanging PASSED ATP-02 SR2.1, Spec1: Storage RTC Memory Boundaries 100% Byte Retention PASSED ATP-03 UR2.2: Biological XAI Spectral Ratio Classification Precision ≥ 0.95 PASSED ATP-04 SR2.3, Spec3: ML Speed Inference Latency ≤ 2.00 Seconds PASSED

### 4.7.1 Onboard Firmware and State Machine Verification (ATP-01 and ATP-02)

The execution of the physical HITL validation was conducted directly on the DFRobot FireBeetle 2 ESP32-C6 hardware workspace. To simulate the subsea magnetic reed switch interrupt within a controlled laboratory environment, an external physical pull-down button was anchored directly to the low-power LP-IO domain on GPIO pin 1 (D6).

The system was intentionally subjected to consecutive deep sleep resets to stress test the memory architecture. Empirical telemetry confirmed that the mission_state and record_counter variables were fully preserved across power-gated boundaries, validating the structural integrity of the RTC_DATA_ATTR mapping [?].

The verified serial monitor execution log is provided below, serving as explicit engineering proof of the deterministic state transitions:

--- ESP32-C6 Antarctic Probe Firmware ---

SYSTEM START: Initial Power-On / Manual Reset

MISSION STATE: 0 (STANDBY)

[HITL] Entering Indefinite Deep Sleep (Waiting for Arming)...

--- ESP32-C6 Antarctic Probe Firmware ---

Diagnostics -> State: 0, Reset: 8, Wakeup: 3

[HITL] STATE 0 -> 1: PROBE ARMED. Sinking to depth...

[HITL] Entering Deep Sleep for 15s...

--- ESP32-C6 Antarctic Probe Firmware ---

Diagnostics -> State: 1, Reset: 8, Wakeup: 0

[HITL] STATE 1 (ARMED): Sinking interval wait (15s)...

[HITL] STATE 1 -> 2: Sinking delay complete. Starting LOGGING.

[HITL] Waking up (Timer/Cycle)...

[HITL] Saving to F-RAM: 1,15000,1400.0,2200.0,...

[HITL] Entering Deep Sleep for 5s...

--- ESP32-C6 Antarctic Probe Firmware ---

Diagnostics -> State: 2, Reset: 8, Wakeup: 0

[HITL] Waking up (Timer/Cycle)...

[HITL] Saving to F-RAM: 2,20000,1400.0,2200.0,...

4.7. Testing and Validation

[HITL] Entering Deep Sleep for 5s...

[HITL] WAKEUP CAUSE: GPIO 1 (Magnetic Switch Simulated)!

[HITL] Offload complete. Returning to STATE 0 (STANDBY).

This log explicitly displays:

1. The initial hardware cold boot (SYSTEM START) and immediate entry into state 0 (STANDBY).
2. The external GPIO wakeup interrupt triggering the state transition to ARMED and configuring the 15-second accelerated sinking delay.
3. The automated transition to state 2 (LOGGING) upon timer expiration, followed by successive 5-second sampling cycles writing packed structures to the RTC memory array.
4. The second manual low interrupt forcing an unmasked wakeup, initiating the state 3 (OFFLOAD) sequence, dumping the records, clearing the non-volatile registers, and smoothly returning to

STANDBY.
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

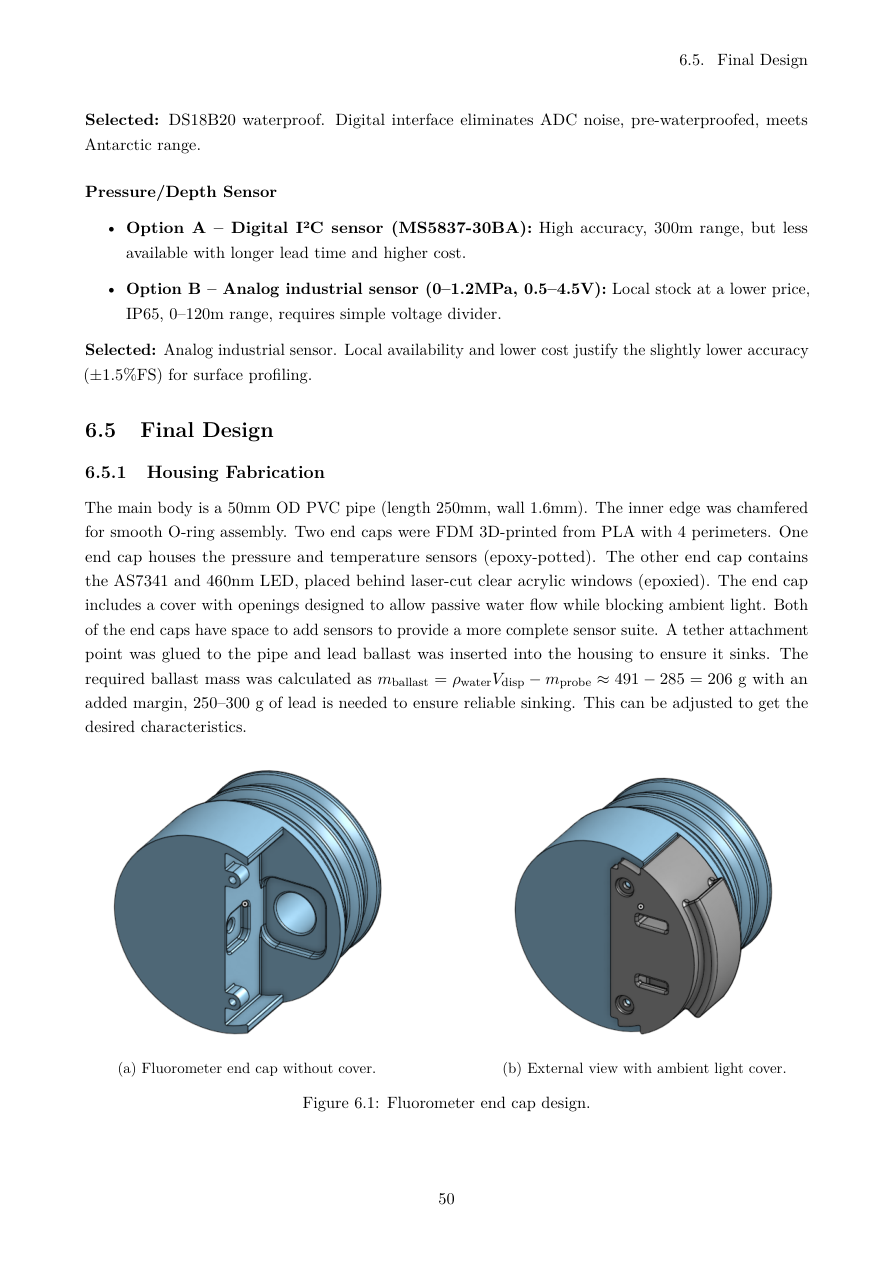
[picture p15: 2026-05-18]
slides_images/page58_full.png

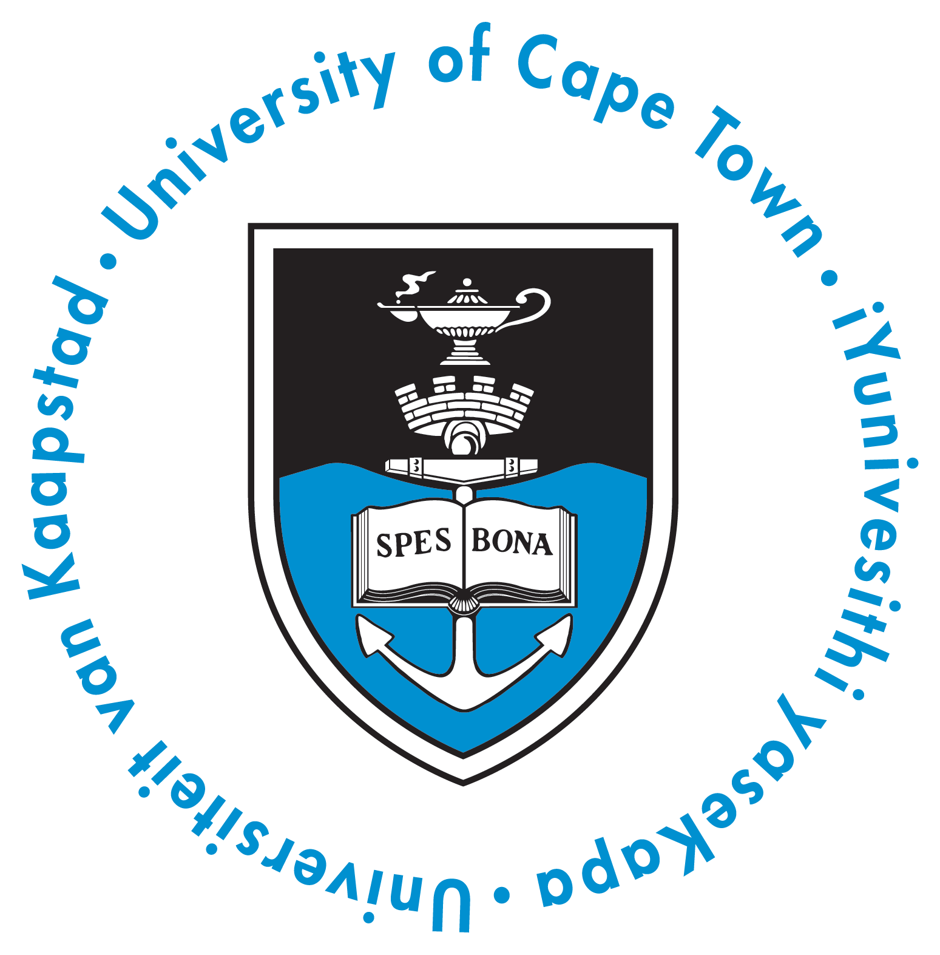
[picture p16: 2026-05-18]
slides_images/page1_img1.png

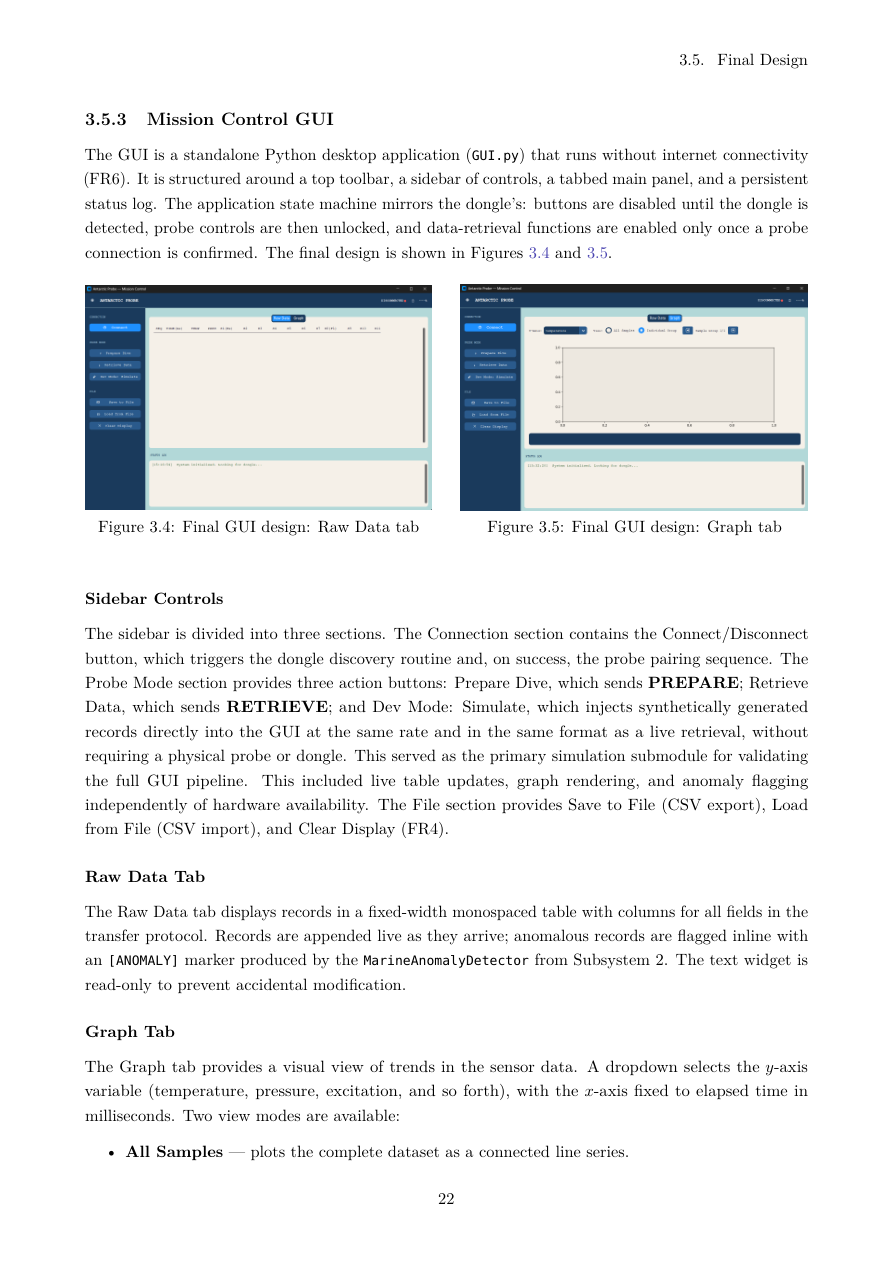
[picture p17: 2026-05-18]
slides_images/page30_full.png

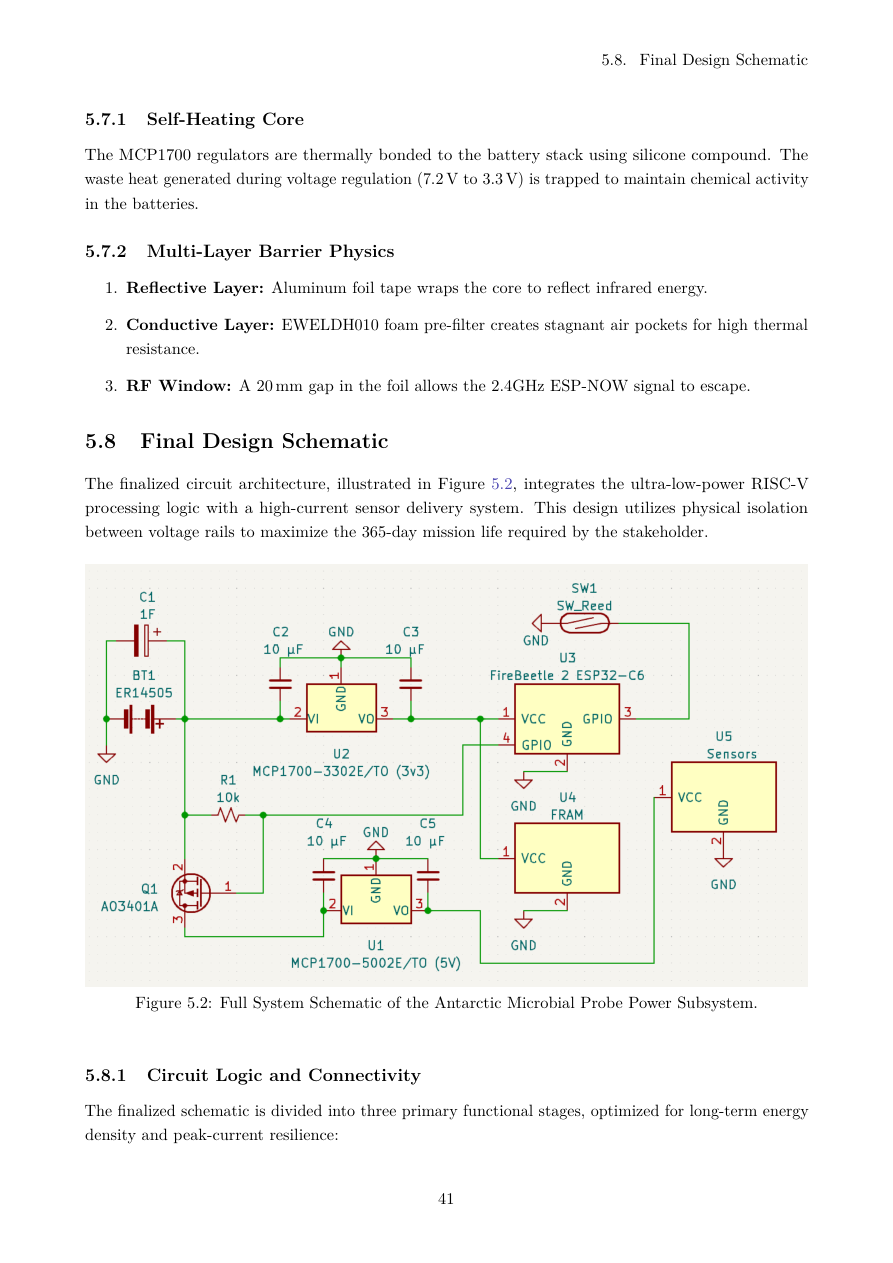
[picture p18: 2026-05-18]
slides_images/page49_full.png

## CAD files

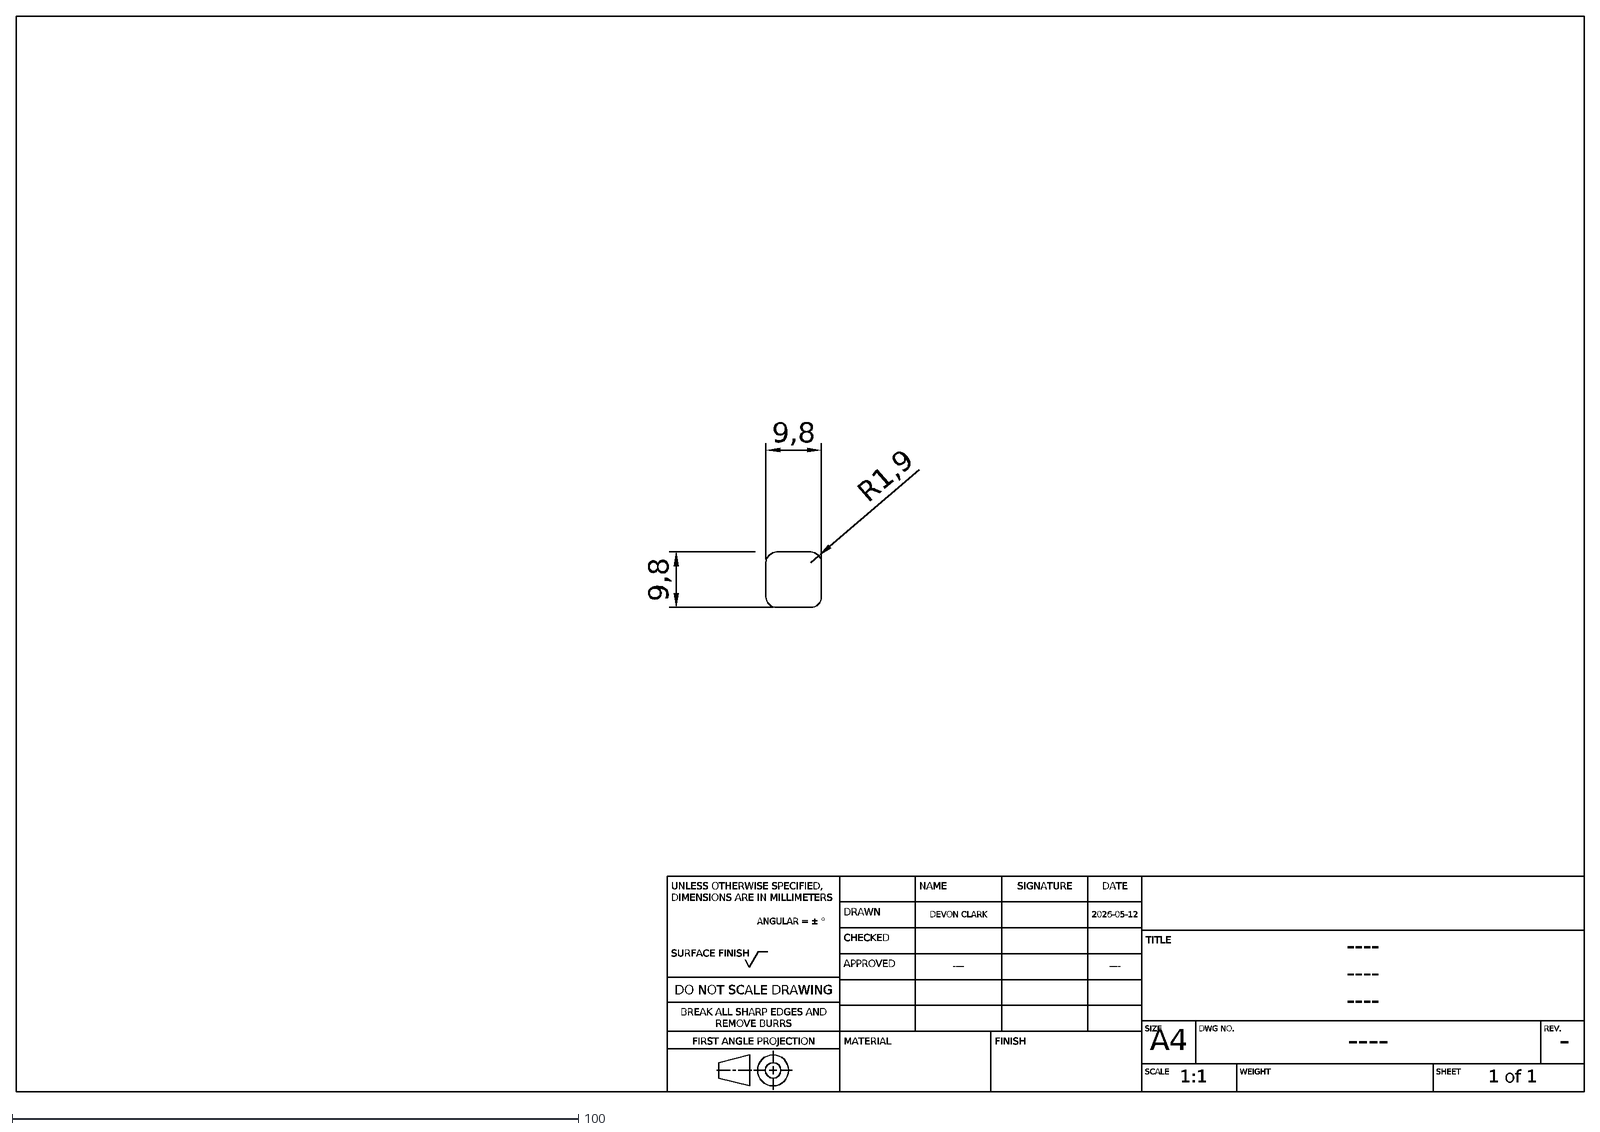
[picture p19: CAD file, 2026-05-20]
Window2.dxf
UNLESS OTHERWISE SPECIFIED, DIMENSIONS ARE IN MILLIMETERS
ANGULAR = ± °
SURFACE FINISH
DO NOT SCALE DRAWING
BREAK ALL SHARP EDGES AND REMOVE BURRS
FIRST ANGLE PROJECTION
SIGNATURE
NAME
DATE
DRAWN
DEVON CLARK
2026-05-12
CHECKED
APPROVED
----
MATERIAL
FINISH
TITLE
SIZE
A4
DWG NO.
REV.
-
SCALE
1:1
WEIGHT
SHEET
1 of 1
9,8
R1,9

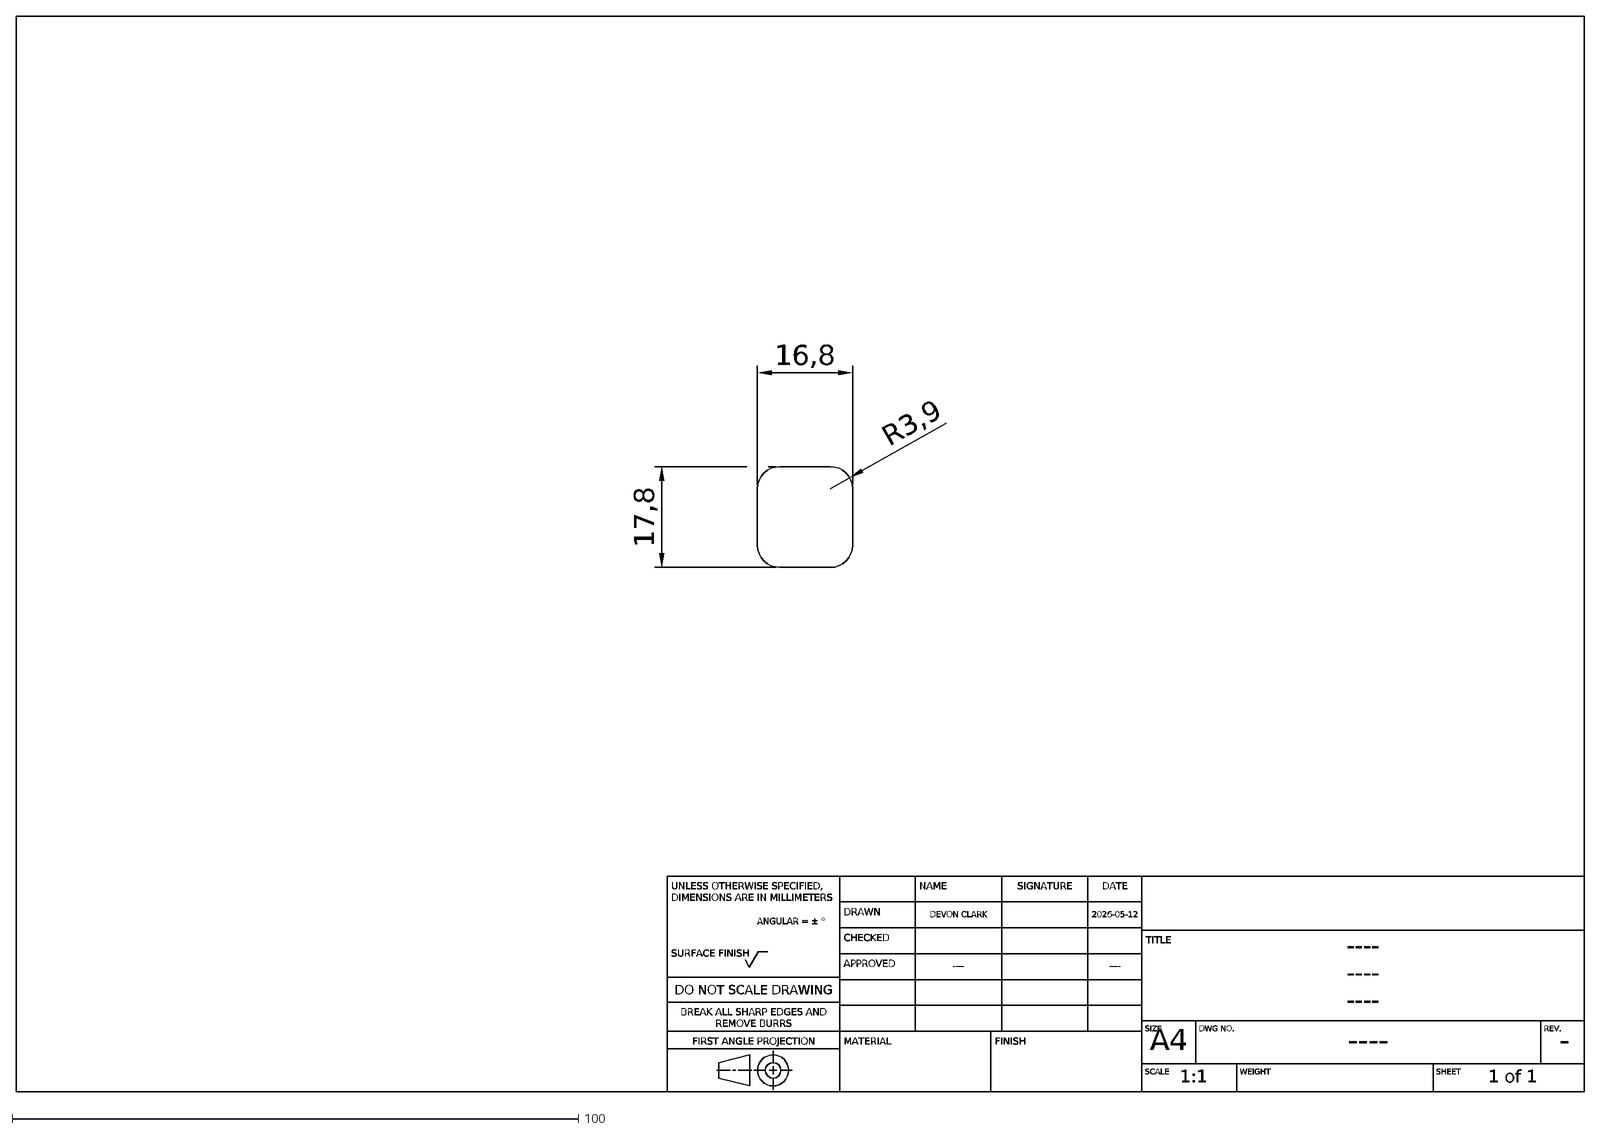
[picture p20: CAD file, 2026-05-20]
Window1.dxf
UNLESS OTHERWISE SPECIFIED, DIMENSIONS ARE IN MILLIMETERS
ANGULAR = ± °
SURFACE FINISH
DO NOT SCALE DRAWING
BREAK ALL SHARP EDGES AND REMOVE BURRS
FIRST ANGLE PROJECTION
SIGNATURE
NAME
DATE
DRAWN
DEVON CLARK
2026-05-12
CHECKED
APPROVED
----
MATERIAL
FINISH
TITLE
SIZE
A4
DWG NO.
REV.
-
SCALE
1:1
WEIGHT
SHEET
1 of 1
16,8
R3,9
17,8

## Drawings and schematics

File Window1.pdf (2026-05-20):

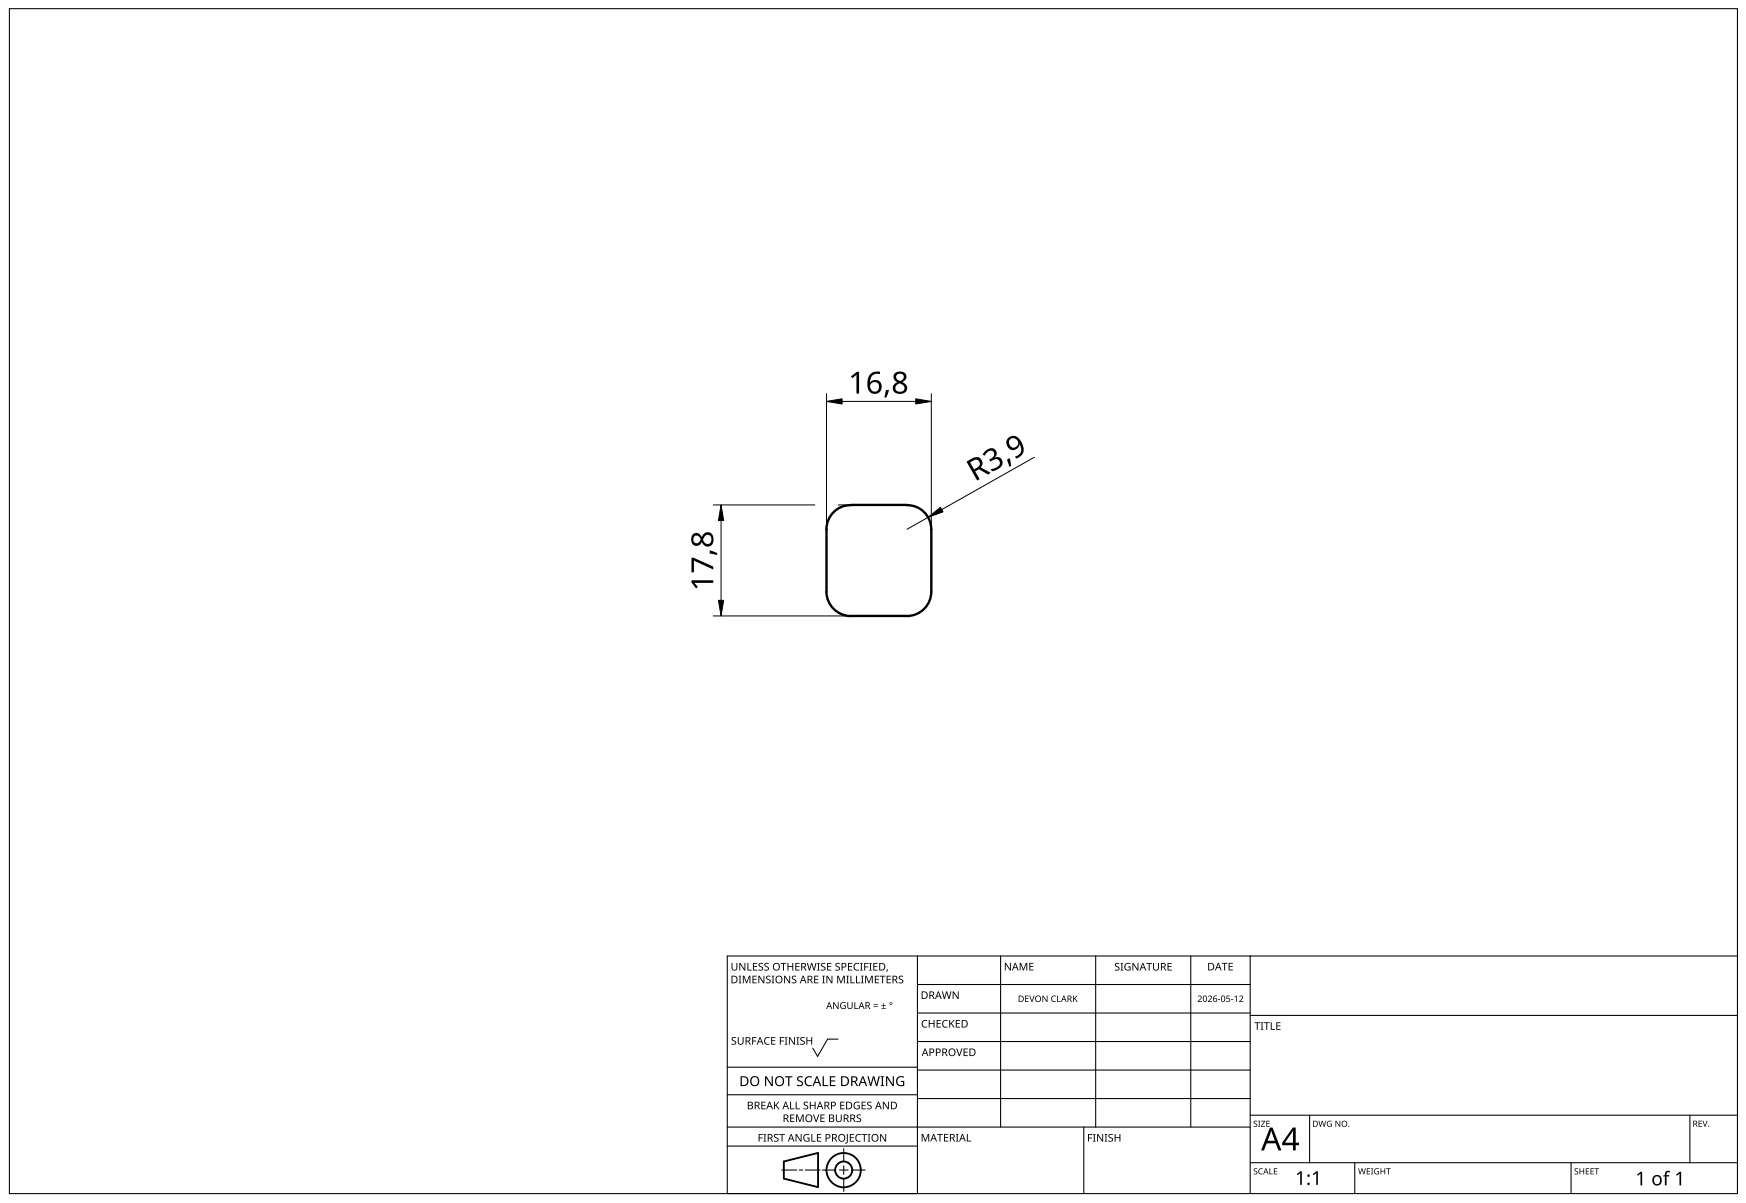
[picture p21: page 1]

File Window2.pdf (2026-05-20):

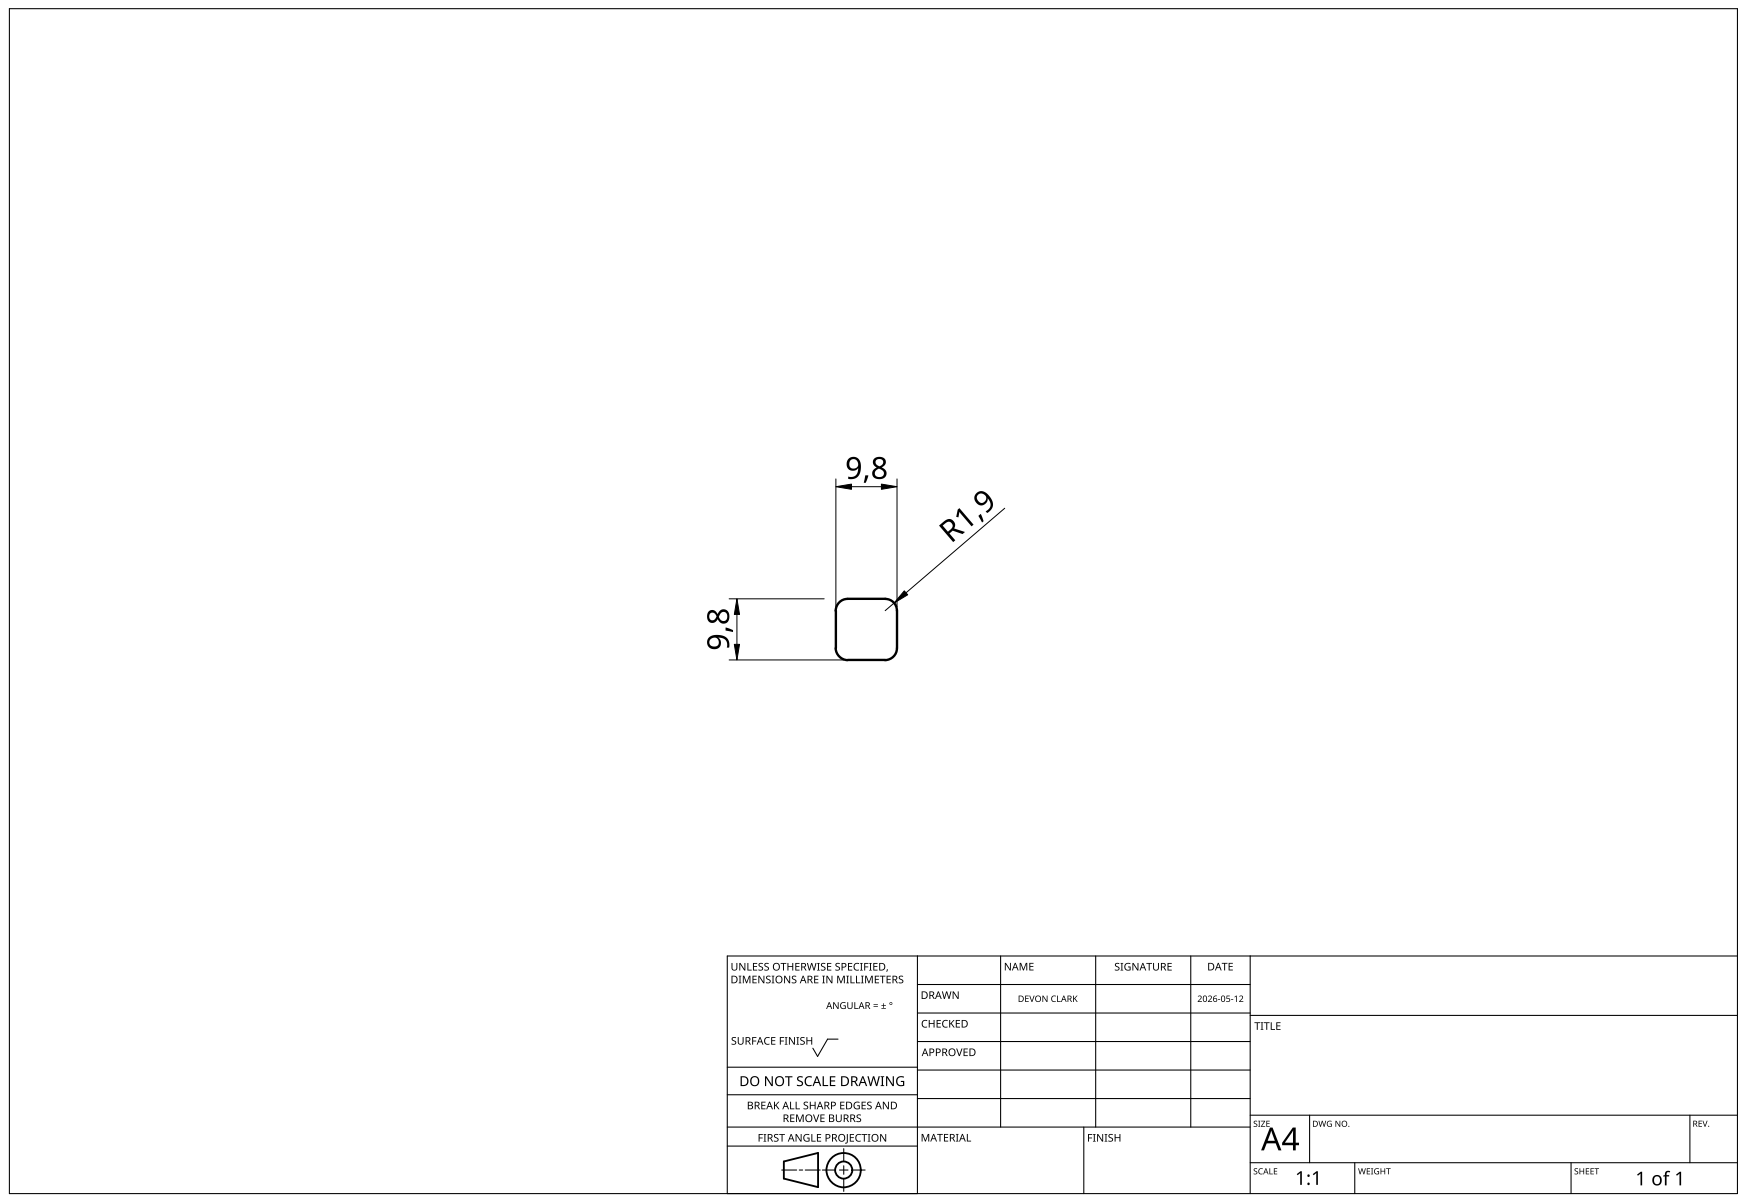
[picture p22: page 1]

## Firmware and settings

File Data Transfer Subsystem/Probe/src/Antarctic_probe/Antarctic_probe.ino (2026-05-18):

#include <Arduino.h>
#include "fram_manager.h"
#include "espnow_transfer.h"
#include "data_packet.h"

// ==============================================================================
// 1. HITL DEBUG CONFIGURATION & MISSION PARAMETERS
// ==============================================================================
#define DEBUG_MODE 1  // Set to 0 for production

#if DEBUG_MODE
    #define SINKING_DELAY_SEC 15
    #define LOGGING_INTERVAL_SEC 5
#else
    #define SINKING_DELAY_SEC 600
    #define LOGGING_INTERVAL_SEC 300
#endif

// MISSION STATES
#define STATE_STANDBY 0
#define STATE_ARMED   1
#define STATE_LOGGING 2

// PIN DEFINITION
#define REED_SWITCH_PIN GPIO_NUM_1  // D6 on FireBeetle 2 C6
#define uS_TO_S_FACTOR 1000000ULL

// Simulated State Persistence (survives deep sleep)
RTC_DATA_ATTR int mission_state = STATE_STANDBY;
RTC_DATA_ATTR int record_counter = 1;
RTC_DATA_ATTR uint32_t session_start_time = 0;
RTC_DATA_ATTR uint32_t global_session_date = 20260515; // YYYYMMDD
RTC_DATA_ATTR char global_session_time[10] = "00:00:00";

/**
 * Mock battery level function.
 */
int get_battery_level() {
    return 70; // Hardcoded as requested
}

/**
 * Handles a command session over ESP-NOW.
 * Returns true if a mission-critical command was processed (PREPARE or RETRIEVE).
 */
bool handle_command_session() {
    Serial.println("[CMD] Entering Command Session. Waiting for CONNECT...");

    if (ESPNOW_Init() != ESPNOW_OK) {
        Serial.println("[CMD] ESP-NOW Init failed.");
        return false;
    }

    bool session_active = true;
    bool action_performed = false;
    uint32_t last_activity = millis();
    const uint32_t TIMEOUT_MS = 60000; // 1 minute timeout

    while (session_active && (millis() - last_activity < TIMEOUT_MS)) {
        char cmd_buf[64];
        if (ESPNOW_GetCommand(cmd_buf, sizeof(cmd_buf))) {
            last_activity = millis();
            String cmd = String(cmd_buf);
            Serial.printf("[CMD] Received: %s\n", cmd_buf);

            if (cmd == "[CMD]:CONNECT") {
                char resp[32];
                snprintf(resp, sizeof(resp), "[ACK]:CONNECT,BATT:%d", get_battery_level());
                ESPNOW_SendString(resp);
                Serial.println("[CMD] Sent CONNECT ACK with battery info.");
            }
            else if (cmd.startsWith("[CMD]:PREPARE")) {
                // Format: [CMD]:PREPARE, 2026-05-13, 12:15:00
                if (cmd.length() >= 29) {
                    String dateStr = cmd.substring(14, 24); // "2026-05-13"
                    String timeStr = cmd.substring(25);     // "12:15:00"

                    // Convert date to YYYYMMDD
                    String y = dateStr.substring(0, 4);
                    String m = dateStr.substring(5, 7);
                    String d = dateStr.substring(8, 10);
                    global_session_date = (y.toInt() * 10000) + (m.toInt() * 100) + d.toInt();

                    strncpy(global_session_time, timeStr.c_str(), sizeof(global_session_time) - 1);

                    Serial.printf("[CMD] Prepared mission: Date=%lu, Time=%s\n", global_session_date, global_session_time);
                    ESPNOW_SendString("[ACK]:PREPARE");
                    action_performed = true;
                    session_active = false; // Exit after prepare to start mission
                }
            }
            else if (cmd == "[CMD]:RETRIEVE") {
                ESPNOW_SendString("[ACK]:RETRIEVE");
                // The actual transfer happens outside this loop or we call it here
                action_performed = true;
                session_active = false;
            }
            else if (cmd == "[CMD]:DISCONNECT") {
                ESPNOW_SendString("[ACK]:DISCONNECT");
                session_active = false;
            }
        }
        delay(10);
    }

    if (millis() - last_activity >= TIMEOUT_MS) {
        Serial.println("[CMD] Session timed out.");
    }

    ESPNOW_Deinit();
    return action_performed;
}

/**
 * Executes the data offload sequence using ESP-NOW.
 */
void handle_offload() {
    Serial.println("\n[HITL] WAKEUP CAUSE: GPIO 1 (Magnetic Switch Simulated)!");

    // 1. Enter Command Session to wait for CONNECT/RETRIEVE
    if (!handle_command_session()) {
        Serial.println("[OFFLOAD] No command received or session failed.");
        return;
    }

    // 2. If we reach here, a command was processed.
    // Note: handle_command_session de-inits ESPNOW, so we need to re-init if we start transfer.
    // Or we could have handle_command_session NOT de-init if RETRIEVE was called.
    // Let's assume RETRIEVE was the action performed.

    ProbeRecord_t* records = (ProbeRecord_t*)malloc(sizeof(ProbeRecord_t) * 100);
    if (records != NULL) {
        int count = fram_get_records(records, 100);
        if (count > 0) {
            if (ESPNOW_Init() == ESPNOW_OK) {
                ESPNOW_StartTransfer(records, count, session_start_time, global_session_date);
                ESPNOW_Deinit();
            }
        } else {
            Serial.println("[OFFLOAD] No records found in F-RAM memory.");
        }
        free(records);
    }

    fram_clear();
    record_counter = 1;
    session_start_time = 0;
    mission_state = STATE_STANDBY;
    Serial.println("[HITL] Offload complete. Returning to STATE 0 (STANDBY).");
    Serial.flush();
}

/**
 * Generates a dummy sensor reading (11-step PWM ramp) and saves it to simulated F-RAM.
 */
void log_sensor_data() {
    Serial.println("[HITL] Waking up (Timer/Cycle) -> Generating 11-step LED PWM ramp...");
    
    uint32_t base_time_ms = (record_counter - 1) * LOGGING_INTERVAL_SEC * 1000;
    
    for (int step = 0; step < 11; step++) {
        uint32_t current_time_ms = base_time_ms + (step * 116); // ~116ms per step
        float temp_c = 20.50;
        float depth_m = 0.100;
        
        // Base values
        float F1 = 15.0 * step;
        float F2 = 350.0 * step; // Excitation ramps up
        float F3 = 200.0 * step;
        float F4 = 18.0 * step;
        float F5 = 10.0 * step;
        float F6 = 8.0 * step;
        float F7 = 13.0 * step;
        float F8 = 25.0 * step;
        float clear = 300.0 * step;
        float NIR = 8.0 * step;

        String dummy_data = String(record_counter) + "," + String(current_time_ms) + "," + 
                            String(temp_c, 2) + "," + String(depth_m, 3) + "," + 
                            String(F1, 0) + "," + String(F2, 0) + "," + String(F3, 0) + "," + 
                            String(F4, 0) + "," + String(F5, 0) + "," + String(F6, 0) + "," + 
                            String(F7, 0) + "," + String(F8, 0) + "," + String(clear, 0) + "," + String(NIR, 0);
                            
        // Serial.println("[HITL] Saving to F-RAM: " + dummy_data); // Suppress to avoid spam, fram_write_record prints it
        fram_write_record(dummy_data);
    }
    
    record_counter++;
    Serial.flush();
}

void setup() {
    // 1. Evaluate wakeup cause immediately
    esp_reset_reason_t reset_reason = esp_reset_reason();
    esp_sleep_wakeup_cause_t wakeup_cause = esp_sleep_get_wakeup_cause();
    pinMode(REED_SWITCH_PIN, INPUT_PULLUP);

    bool is_deepsleep = (reset_reason == ESP_RST_DEEPSLEEP);
    bool is_button = (wakeup_cause == ESP_SLEEP_WAKEUP_EXT1 || wakeup_cause == ESP_SLEEP_WAKEUP_GPIO);
    bool is_spurious = (is_deepsleep && wakeup_cause == ESP_SLEEP_WAKEUP_UNDEFINED);

    // 2. Robust Serial Initialisation
    Serial.begin(115200);
    uint32_t wait_start = millis();
    // Give the USB-CDC plenty of time to stabilize on the host
    while (!Serial && (millis() - wait_start < 2000));
    delay(500);

    // --- SPURIOUS WAKEUP SUPPRESSION ---
    // If it's just noise, go back to sleep with minimal chatter
    if (is_spurious && mission_state == STATE_STANDBY) {
        // We print a single dot to show the chip is alive but looping
        Serial.print(".");
        goto sleep_transition;
    }

    Serial.println("\n\n--- ESP32-C6 Antarctic Probe Firmware ---");

    if (!is_deepsleep) {
        Serial.println("SYSTEM START: Initial Power-On / Manual Reset");
        Serial.println("MISSION STATE: 0 (STANDBY)");
        fram_init();
        fram_clear();
        record_counter = 1;
        session_start_time = 0;
        mission_state = STATE_STANDBY;
    } else {
        Serial.printf("Diagnostics -> State: %d, Reset: %d, Wakeup: %d\n", mission_state, (int)reset_reason, (int)wakeup_cause);
        fram_init();

        // --- STATE 0: STANDBY ---
        if (mission_state == STATE_STANDBY) {
            if (is_button) {
                Serial.println("[HITL] STATE 0 Triggered: Entering PRE-DEPLOYMENT Command Session...");
                if (handle_command_session()) {
                    Serial.println("[HITL] PREPARE Complete. Mission ARMED. Sinking...");
                    mission_state = STATE_ARMED;
                    session_start_time = millis();
                    Serial.flush();
                    delay(1000);
                } else {
                    Serial.println("[HITL] Command session aborted. Staying in STANDBY.");
                }
            }
        }
        // --- STATE 1: ARMED (Sinking) ---
        else if (mission_state == STATE_ARMED) {
            if (is_button) {
                // If button pressed during ARMED, jump straight to logging
                Serial.println("[HITL] Manual Trigger: Bypassing sinking delay.");
                mission_state = STATE_LOGGING;
                log_sensor_data();
            } else {
                Serial.printf("[HITL] STATE 1 (ARMED): Sinking interval wait (%ds)...\n", SINKING_DELAY_SEC);
                Serial.flush();
                // Real-time polling wait
                uint32_t sinking_start = millis();
                while (millis() - sinking_start < (SINKING_DELAY_SEC * 1000)) {
                    if (digitalRead(REED_SWITCH_PIN) == LOW) {
                        Serial.println("[HITL] Sinking interrupted by manual trigger.");
                        break;
                    }
                    delay(10);
                }
                Serial.println("[HITL] STATE 1 -> 2: Sinking delay complete. Starting LOGGING.");
                mission_state = STATE_LOGGING;
                log_sensor_data();
            }
        }
        // --- STATE 2: LOGGING ---
        else if (mission_state == STATE_LOGGING) {
            if (is_button) {
                handle_offload();
            } else {
                Serial.printf("[HITL] STATE 2 (LOGGING): Cycle wait (%ds). Press D6 to offload.\n", LOGGING_INTERVAL_SEC);
                Serial.flush();
                uint32_t logging_start = millis();
                bool triggered = false;
                while (millis() - logging_start < (LOGGING_INTERVAL_SEC * 1000)) {
                    if (digitalRead(REED_SWITCH_PIN) == LOW) {
                        handle_offload();
                        triggered = true;
                        break;
                    }
                    delay(10);
                }
                if (!triggered) log_sensor_data();
            }
        }
    }

    sleep_transition:
    // --- FINAL SLEEP PREPARATION ---
    esp_sleep_enable_ext1_wakeup(1ULL << REED_SWITCH_PIN, ESP_EXT1_WAKEUP_ANY_LOW);

    if (mission_state == STATE_STANDBY) {
        if (!is_spurious) Serial.println("[HITL] Entering Indefinite Deep Sleep (Waiting for Arming)...");
    } else {
        int sleep_time = (mission_state == STATE_ARMED) ? SINKING_DELAY_SEC : LOGGING_INTERVAL_SEC;
        Serial.printf("[HITL] Entering Deep Sleep for %ds...\n", sleep_time);
        esp_sleep_enable_timer_wakeup((uint64_t)sleep_time * uS_TO_S_FACTOR);
    }

    Serial.flush();
    delay(1000); // CRITICAL: Stability delay for USB-CDC PHY shutdown
    esp_deep_sleep_start();
}

void loop() {}

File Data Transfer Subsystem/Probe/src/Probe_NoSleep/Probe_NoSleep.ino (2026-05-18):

#include <Arduino.h>
#include <WiFi.h>
#include "fram_manager.h"
#include "espnow_transfer.h"
#include "data_packet.h"

// =============================================================================
// Test sketch: probe runs continuously with no deep sleep.
// ESP-NOW is initialised immediately on boot and stays on.
// 20 dummy records are pre-loaded at startup.
// The dongle can connect and retrieve at any time via ESP-NOW commands.
// =============================================================================

#define PRELOAD_RECORDS 20

static int      record_counter     = 1;
static uint32_t session_start_time = 0;
static uint32_t session_date       = 20260518; // YYYYMMDD

int get_battery_level() { return 70; }

void log_sensor_data() {
    uint32_t ms = (uint32_t)(record_counter - 1) * 5000;
    String data = String(record_counter) + "," + String(ms) +
                  ",1400.0,2200.0,100.0,105.0,90.0,110.0,95.0,100.0,120.0,80.0,90.0,110.0,105.0";
    Serial.println("[PROBE] Logging: " + data);
    fram_write_record(data);
    record_counter++;
}

void do_offload() {
    ProbeRecord_t* records = (ProbeRecord_t*)malloc(sizeof(ProbeRecord_t) * 100);
    if (!records) {
        Serial.println("[PROBE] malloc failed.");
        return;
    }
    int count = fram_get_records(records, 100);
    if (count > 0) {
        ESPNOW_StartTransfer(records, count, session_start_time, session_date);
    } else {
        Serial.println("[PROBE] No records to send.");
    }
    free(records);

    fram_clear();
    record_counter     = 1;
    session_start_time = millis();

    Serial.printf("[PROBE] Re-loading %d records for next retrieval...\n", PRELOAD_RECORDS);
    for (int i = 0; i < PRELOAD_RECORDS; i++) {
        log_sensor_data();
    }
}

void setup() {
    Serial.begin(115200);
    delay(500);
    Serial.println("\n--- Probe NoSleep Test Mode ---");

    fram_init();
    fram_clear();
    record_counter     = 1;
    session_start_time = millis();

    if (ESPNOW_Init() != ESPNOW_OK) {
        Serial.println("[ERROR] ESP-NOW init failed. Halting.");
        while (true) delay(1000);
    }

    Serial.print("[PROBE] MAC Address: ");
    Serial.println(WiFi.macAddress());

    Serial.printf("[PROBE] Pre-loading %d records...\n", PRELOAD_RECORDS);
    for (int i = 0; i < PRELOAD_RECORDS; i++) {
        log_sensor_data();
    }

    Serial.println("[PROBE] Ready. Listening for ESP-NOW commands.");
}

void loop() {
    char cmd_buf[64];
    if (ESPNOW_GetCommand(cmd_buf, sizeof(cmd_buf))) {
        String cmd = String(cmd_buf);
        Serial.printf("[CMD] Received: %s\n", cmd_buf);

        if (cmd == "[CMD]:CONNECT") {
            char resp[32];
            snprintf(resp, sizeof(resp), "[ACK]:CONNECT,BATT:%d", get_battery_level());
            ESPNOW_SendString(resp);

        } else if (cmd == "[CMD]:RETRIEVE") {
            ESPNOW_SendString("[ACK]:RETRIEVE");
            do_offload();

        } else if (cmd == "[CMD]:DISCONNECT") {
            ESPNOW_SendString("[ACK]:DISCONNECT");
        }
    }
}

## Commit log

2026-05-03 GUI v0 + BLE server (broken)
    Basic GUI with functionality created. No BLE code added to it yet.
    BLE server code advertising but problems connecting to board
    [Antarctic_probe.ino, GUI.py]
2026-05-05 Initialize README with project details and structure
    Added detailed project overview, repository structure, and subsystem descriptions for the Antarctic Submersible Probe mission control system.
2026-05-08 Task 1.1: Generate dummy marine dataset for Anomaly Detection
    Created generate_dummy_data.py to build a 5,050 row dataset mapping to the 15-value string format. Injected 50 anomalous rows into Spectrometer channels 6 and 7. Updated STATUS_REPORT.md with the lat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
    [dummy_marine_data.csv]
2026-05-09 Task 1.2: Train and export Isolation Forest model for anomaly detection
    Implemented train_model.py to ingest dummy data, filter temporal features, and train an Isolation Forest model. Validated with 1.00 overall accuracy against ground truth anomalies, and exported the m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
2026-05-10 Task 2.1 - 2.3: Implement ESP32-C6 Onboard Firmware logic
    Added PlatformIO setup targeting FireBeetle ESP32-C6. Created fram_manager HAL for F-RAM simulation via RTC memory. Implemented main state machine (DEEP_SLEEP, WAKE_AND_LOG, OFFLOAD) with non-blockin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
2026-05-10 GUI absorbed probe_interface
    Backend.py and GUI now is all thats needed to communicate with the dongle
2026-05-10 Fix Native USB serial connection hang and missing mock status function
    - receiver_dongle.ino: Added a continuous "[INFO] Ready..." heartbeat in the `loop()` function. The FireBeetle ESP32-C6 uses Native USB, meaning the board does not auto-reset when PySerial opens the connection. The heartbeat ensures the Python script can detect the dongle even if it misses the initial setup print.
    - Backend.py: Added the missing mock_get_status() async function. The GUI was calling this function upon clicking "Connect", causing a crash because the function was undefined.
    - Backend.py: Explicitly asserted DTR and RTS lines to True in 'connect_dongle()' to ensure the Native USB stack is allowed to transmit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
    [Backend.py]
2026-05-11 Phase 3 Integration: Spliced ML Anomaly Detector into GUI Backend and updated F-RAM state machine in probe firmware.
    - Re-architected ProbeRecord_t across the firmware to support a full 15-channel payload.
    - Merged kiyuran_firmware/main.cpp into Antarctic_probe.ino implementing a non-blocking 3-state firmware loop.
    - Modifed receiver_dongle.ino to output 15-channel CSV strings.
    - Updated GUI/Backend.py to evaluate anomaly dynamically using MarineAnomalyDetector.
    - Modified GUI/GUI.py to flag anomalous points with a red scatter overlay and text tag.
2026-05-11 Added Dev Mode simulation to GUI to test ML integration without physical ESP-NOW link.
    - Added simulate_incoming_data() to Backend.py to dynamically ingest the dummy CSV dataset.
    - The simulator artificially spaces packet generation by 0.5s to mimic hardware serial bottlenecks.
    - Wired a new 'Dev Mode: Simulate' button in GUI.py.
    - Implemented a live _handle_live_record callback to allow the GUI telemetry dashboard and matplotlib scatter plots to render incoming records (and highlight anomalies) in real-time.
2026-05-11 Task 4.2: Implemented Simulation Playback Controls.
    - Added threading.Event flags (_sim_paused, _sim_stopped) to Backend.py to safely govern the data ingestion thread.
    - Created Backend control methods (pause_simulation, resume_simulation, stop_simulation).
    - Dynamically replaced the GUI 'Dev Mode' button with a Play/Pause, Stop, and Restart control panel array when simulation starts.
    - Polling in 0.1s increments adheres to Event-Driven UI paradigms, ensuring no deadlock or freezing in CustomTkinter.
    - Updated README.md with the playback control usage instructions.
    [Backend.py, GUI.py]
2026-05-11 Dev mode layout fix
    [GUI.py]
2026-05-11 Task 4.3: Implemented Hardware-in-the-Loop (HITL) Debug Mode.
    - Added DEBUG_MODE macro to Antarctic_probe.ino for accelerated testing (5s sleep).
    - Mapped FireBeetle 2 BOOT button (GPIO 9) as the external wake-up source to simulate reed switch.
    - Instrumented WAKE_AND_LOG and OFFLOAD states with verbose serial output (115200 baud).
    - Updated fram_manager.cpp to print raw RTC memory strings during HITL retrieval.
    - Relocated platformio.ini and restructured Probe directory for seamless PlatformIO IDE integration.
    - Updated README.md with HITL testing procedures.
2026-05-11 Fix compilation errors for ESP32-C6 and Arduino Core 3.x.
    - Updated ProbeRecord_t static_assert to 62 bytes.
    - Added session_date to SessionHeader_t to match ESP-NOW implementation.
    - Refactored ESP-NOW callbacks for Arduino Core 3.0+ (IDF 5.x) compatibility.
    - Replaced unsupported ext0 sleep wakeup with ext1 for the C6 architecture.
    - Synchronized ESPNOW_Deinit and ESPNOW_StartTransfer signatures across .h and .cpp.
    [Antarctic_probe.ino, espnow_transfer.cpp]
2026-05-11 Fix ESP32-C6 Deep Sleep wakeup limitation and Serial log truncation.
    - Switched REED_SWITCH_PIN to GPIO 7 (LP IO) because GPIO 9 (BOOT) is not an RTC pin on C6.
    - Added record_counter reset on physical reset (OTHER wakeup cause).
    - Increased startup delay to 2000ms for stable USB-Serial reconnection.
    - Added 100ms delay before deep sleep to ensure Serial buffer flushes correctly.
    [Antarctic_probe.ino]
2026-05-11 Task 4.3 Continued: Fixed GPIO 9 deep sleep wakeup and Serial sync on C6.
    - Replaced ext1 with esp_deep_sleep_enable_gpio_wakeup for digital-only GPIO 9 support on ESP32-C6.
    - Added Serial synchronization loop in setup() to wait for USB-CDC re-enumeration.
    - Implemented record_counter and F-RAM simulation reset on manual boot to ensure clean test state.
    [Antarctic_probe.ino]
2026-05-11 Task 4.3 Continued: Implemented Light Sleep + Restart workaround for C6 GPIO 9.
    - Resolved 'invalid deep sleep wakeup IO' error for GPIO 9 on ESP32-C6.
    - In DEBUG_MODE, firmware now enters Light Sleep (supporting GPIO 9) and triggers esp_restart() upon wakeup.
    - Preserves the Deep Sleep state machine flow (reset to setup()) via RTC-persisted hitl_wakeup_cause flag.
    [Antarctic_probe.ino]
2026-05-11 Task 4.3 Continued: Switched HITL trigger to LP IO GPIO 0 for true Deep Sleep.
    - Reverted Light Sleep workaround as it caused USB-Serial re-enumeration hangs.
    - Mapped REED_SWITCH_PIN to GPIO 0 (AD0), enabling standard ext1 deep sleep wakeup.
    - Optimized Serial wait-loop (5s) for more reliable telemetry capture after sleep cycles.
    [Antarctic_probe.ino]
2026-05-11 Task 4.3 Continued: Switched HITL trigger to external button on GPIO 0.
    - Reverted Light Sleep hack in favor of native Deep Sleep on LP-IO (GPIO 0).
    - Configured ext1 wakeup for GPIO 0 (D2) to support deep sleep wakeup on C6.
    - Enhanced Serial synchronization to 4 seconds to resolve USB-CDC reconnection issues.
    [Antarctic_probe.ino]
2026-05-11 Task 4.3 Continued: Corrected pin mapping to D6 (GPIO 1) for C6 FireBeetle.
    - Re-mapped REED_SWITCH_PIN to GPIO 1 (D6) after verifying schematics.
    - GPIO 1 is a valid LP-IO (RTC IO) on C6, enabling Deep Sleep wakeup.
    - Updated HITL wiring instructions to D6 for hardware validation.
    [Antarctic_probe.ino]
2026-05-11 Task 4.3 Continued: Optimized reset logic and added boot diagnostics.
    - Added esp_reset_reason() to debug boot loop behavior.
    - Prevented F-RAM simulation from clearing on standard software resets/reboots.
    - Enabled RTC_PERIPH power domain to stabilize pull-ups on GPIO 1 during sleep.
    - Added safety hang after esp_deep_sleep_start() to detect sleep entry failure.
    [Antarctic_probe.ino]
2026-05-11 Task 4.3 Continued: Fixed Timer wakeup misreporting on ESP32-C6.
    - Combined Reset Reason 8 (Deep Sleep) with Wakeup Cause 0 as a Timer event.
    - Ensures the WAKE_AND_LOG state triggers even if the specific timer cause is hidden.
    - Preserves HITL data generation cycle across deep sleep periods.
    [Antarctic_probe.ino]
2026-05-11 Task 4.3 Continued: Resolved F-RAM truncation and sleep instability.
    - Increased MAX_PAYLOAD_SIZE to 128 bytes to prevent sensor string truncation.
    - Added 1s pre-sleep delay to stabilize USB-CDC PHY on ESP32-C6.
    - Removed unstable RTC power domain config to prevent instant reboots.
    - Verified successful parsing and offload of mission records during HITL.
    [Antarctic_probe.ino, fram_manager.cpp]
2026-05-11 Task 4.3 Continued: Fixed Stack Protection Fault and optimized sleep entry.
    - Migrated large ProbeRecord_t array to the heap to prevent stack overflow panics.
    - Increased pre-sleep delay to 2000ms to stabilize USB-CDC PHY on C6.
    - Refined wakeup logic to handle timer misreporting and GPIO causes separately.
    [Antarctic_probe.ino]
2026-05-11 Task 4.3 Continued: Switched HITL trigger to A1 (GPIO 2) and optimized stability.
    - Re-mapped REED_SWITCH_PIN to GPIO 2 (A1) to resolve D6 instability.
    - Increased pre-sleep delay to 3000ms for robust USB-CDC handling.
    - Added explicit gpio_set_pull_mode for Deep Sleep pull-up reinforcement.
    [Antarctic_probe.ino]
2026-05-12 Task 4.3 Continued: Fix USB-CDC implicit deep sleep wakeup on ESP32-C6. Root cause was ESP-IDF 5.x registering USB-JTAG as default wakeup source; host PC keep-alive packets immediately woke the chip.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
    [Antarctic_probe.ino]
2026-05-12 Task 4.3 Continued: Implemented Software-Assisted Deep Sleep Timing.
    - Fixed C6 'Instant Wakeup' bug by enforcing the 5s interval in setup().
    - Handles spurious USB-CDC wakeups (Cause 0) while maintaining HITL timeline.
    - Ensures consistent sensor record generation every 5 seconds.
    [Antarctic_probe.ino]
2026-05-12 Task 4.3 Continued: Implemented interactive button polling during HITL wait.
    - Replaced blocking delay() with non-blocking polling of D6 during interval.
    - Allows immediate offload trigger without waiting for the 5s timer to expire.
    - Refactored offload logic into handle_offload() for better state management.
    - Finalized hardware-in-the-loop validation for ESP32-C6 firmware.
    [Antarctic_probe.ino]
2026-05-12 Task 4.3 Continued: Refined HITL output for clean Proof-of-Concept.
    - Re-ordered setup() to remain silent during the simulated 5s sleep interval.
    - Diagnostics and logging now only appear after the interval (or on trigger).
    - Added descriptive logging for the GPIO 1 (Magnetic Switch) trigger.
    - Fixed 'immediate output' bug caused by C6 USB-CDC wakeup interference.
    [Antarctic_probe.ino]
2026-05-12 Task 4.3 Continued: Finalized clean reset and logging system.
    - Implemented automatic F-RAM clear and counter reset on hardware RST.
    - Distinguishes between mission cycles and fresh deployment starts.
    - Refined serial logging for intuitive state and process descriptions.
    - Finalized HITL validation firmware for Antarctic probe mission.
    [Antarctic_probe.ino]
2026-05-12 Task 4.3 Continued: Resolved Serial truncation on manual reset.
    - Added 3s wait-for-serial handshake on initial boot/manual reset.
    - Implemented a prominent SYSTEM START banner for clear deployment resets.
    - Ensured F-RAM and mission counters are fully purged on hardware reset.
    - Optimized Serial synchronization for C6 internal USB-CDC JTAG.
    [Antarctic_probe.ino]
2026-05-12 Task 4.4: Implemented Real-World 4-State Mission Lifecycle.
    - Refactored firmware to include STANDBY, ARMED, LOGGING, and OFFLOAD states.
    - Integrated RTC-persisted mission_state tracking across deep sleep resets.
    - Added 15s sinking delay (ARMED state) to simulate physical deployment.
    - Optimized power floor by disabling timer wakeup in STANDBY state.
    - Updated all serial strings to UK English (e.g., initialised, optimised).
    [Antarctic_probe.ino]
2026-05-12 Task 4.4 Continued: Resolved compilation error and refactored logging.
    - Fixed 'jump to label' error by refactoring logging into log_sensor_data().
    - Improved modularity of the 4-state mission lifecycle logic.
    - Finalized UK English localization and diagnostic reporting.
    [Antarctic_probe.ino]
2026-05-12 Task 4.4 Continued: Optimized HITL for professional PoC fidelity.
    - Implemented Silent Spurious Wakeup handling for STANDBY state.
    - Re-ordered mission delays to occur BEFORE diagnostic logs.
    - Eliminated connect/disconnect serial noise during sinking and logging.
    - Finalized UK English localization and state machine transitions.
    [Antarctic_probe.ino]
2026-05-12 Task 4.4 Continued: Resolved goto compilation error and finalized PoC.
    - Removed goto sleep_transition to avoid variable initialization conflicts.
    - Wrapped mission logic in a clean conditional block for spurious wakeup handling.
    - Maintained all professional PoC refinements (Silent STANDBY, Delays-First).
    [Antarctic_probe.ino]
2026-05-12 Task 4.4 Continued: Finalized Serial synchronization and PoC prompts.
    - Restored the interactive logging prompt during the 5s mission cycle.
    - Added deliberate Serial flushes and delays after state transitions.
    - Fixed the missing 'STATE 0 -> 1' arming message truncation.
    - Optimized the serial handshake for ESP32-C6 USB-CDC stability.
    - Finalized all mission state reporting in UK English.
    [Antarctic_probe.ino]
2026-05-12 Task 4.4 Continued: Implemented rock-solid Serial synchronization.
    - Added stability delays and Serial.flush() to prevent log truncation.
    - Resolved buffer overlaps caused by quick C6 wakeup-sleep cycles.
    - Implemented 'dot' indicators for silent STANDBY loops.
    - Optimized mission state reporting for professional PoC clarity.
    [Antarctic_probe.ino]
2026-05-15 Documentation Update: Clarified SS2-to-SS1 data handover.
    - Updated Antarctic_probe.ino and fram_manager.cpp with comprehensive comments.
    - Explicitly documented the 15-value record structure (2 uint32, 13 floats).
    - Verified and labeled the ProbeRecord_t array population for Saeed's ESP-NOW transfer logic.
2026-05-15 Logic errors fixed
    TestDongle.ino startsWith("[ACK]:CONNECT") — dongle no longer deadlocks after connect
    Backend.py Removed 20s dead wait from send_prepare_dive
    Backend.py send_retrieve now returns bool instead of None
    GUI.py Save/load use spec1–spec11 keys (was excitation/fluorescence → KeyError crash)
    anomaly_detector.py int(float(...)) instead of int(...) — ML detection now works on real dongle data
    [Backend.py, GUI.py, TestDongle.ino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]
2026-05-16 Phase 5: Upgraded Edge ML Architecture to 14-value 11-step ramp.
    - Refactored C++ ProbeRecord_t and fram_manager to 14 values (10 spectral channels).
    - Updated onboard simulator to generate 11-step LED ramps.
    - Rewrote generate_dummy_data.py to mirror physical AS7341 behaviour and inject biological anomalies.
    - Retrained Isolation Forest model on 14-column dataset (92% accuracy).
    - Implemented Explainable AI (XAI) determinist classification in anomaly_detector.py.
    - Refactored Python GUI backend to map exactly to the new data dict.
    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
    [dummy_marine_data.csv]
2026-05-16 Refinement: Updated SAMPLES_PER_GROUP to 11 and improved XAI labels.
    - Fixed alignment of Individual Group graph view by setting group size to 11 steps.
    - Renamed 'Unknown Anomaly' to 'Non-Biological Variance / Sensor Artifact' for better academic clarity.
    - Updated STATUS_REPORT.md with final validation details.
    [GUI.py]
2026-05-16 XAI Calibration: Adjusted biological thresholds and dummy data.
    - Recalibrated XAI thresholds based on Devon's physical AS7341 sensor baseline tests (F8/F2 > 0.075, etc).
    - Refined generate_dummy_data.py to inject structured biological anomalies instead of random noise, evenly distributing 50 sequences among Phyto, CDOM, and Cyano.
    - Retrained Isolation Forest model on the newly structured dataset to prevent false Non-Biological Variance reporting.
    - Updated STATUS_REPORT.md with the calibration details.
    [dummy_marine_data.csv]
